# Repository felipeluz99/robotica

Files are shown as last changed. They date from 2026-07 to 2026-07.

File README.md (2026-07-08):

# Empilhadeira Autônoma

Turma 3VB - Grupo 3

Felipe Luz machado
Gabriel Cavalleiro
Henrique Conti
Lucas Erbisti

Documentação do projeto de uma empilhadeira capaz de operar em
dois modos: **controle manual** por um operador (via celular ou navegador) e
**busca automática** de um alvo marcado com uma etiqueta AprilTag, usando visão
computacional.

O objetivo deste documento é explicar como o sistema foi
organizado, o papel de cada peça de software e as ideias de controle por trás da
navegação autônoma.

---

## 1. Visão geral do sistema

O sistema é dividido em três programas que rodam em máquinas diferentes e
conversam entre si:

| Arquivo | Onde roda | Papel |
|---|---|---|
| `index.html` | Navegador (celular/PC) | Interface do operador: joysticks, botões e painel de estado |
| `app.py` | Raspberry Pi 3 | "Cérebro": servidor web, visão computacional (AprilTag) e máquina de estados da missão |
| `motor.cpp` | ESP32-WROOM | "Medula": leitura dos encoders/giroscópio e controle PID dos motores |

A ideia central é uma **divisão de responsabilidades por camada**:

- O **navegador** só cuida da interface e envia a intenção do operador.
- A **Raspberry Pi** decide *o que fazer* (procurar, girar, alinhar), mas não
  fala diretamente com os motores.
- O **ESP32** cuida da parte de tempo real *duro*: ler encoders, fechar o laço
  PID de velocidade e acionar as pontes H. Ele nunca decide a estratégia da
  missão; apenas obedece a comandos simples de `throttle` (avanço), `yaw` (giro)
  e `fork` (garfo).

```mermaid
flowchart LR
    A[Celular / Navegador<br/>index.html] -- WebSocket / Socket.IO --> B[Raspberry Pi 3<br/>app.py]
    B -- USB serial / JSON --> C[ESP32-WROOM<br/>motor.cpp]
    C -- Telemetria JSON --> B
    B -- status / apriltags --> A
    D[Câmera USB] --> B
    E[Encoders + MPU6050] --> C
    C --> F[Motores M1 / M2 / M3]
```

Existem, portanto, **dois canais de comunicação distintos**:

1. **Navegador ⇄ Raspberry Pi:** WebSocket (biblioteca Socket.IO).
2. **Raspberry Pi ⇄ ESP32:** porta serial USB, trocando linhas de texto em
   formato JSON.

---

## 2. O robô por dentro (hardware controlado)

O ESP32 controla três motores DC com encoder de quadratura:

- **M1 e M2** — rodas de tração (lado esquerdo e direito). A locomoção é
  **diferencial**: avançar é girar as duas rodas juntas; virar é girar uma mais
  que a outra.
- **M3** — motor do **garfo** (subir/descer a carga).

Cada motor tem uma ponte H com dois pinos de direção e um pino de PWM
(`enable`). O ESP32 também lê um giroscópio/acelerômetro **MPU6050** por I²C, que
fornece o ângulo de rotação (yaw) usado para fechar giros precisos de 90° e 180°
no modo automático.

Os pinos principais definidos em `motor.cpp`:

| Função | GPIO |
|---|---|
| M1 — direção A / B / PWM | 12 / 14 / 13 |
| M1 — encoder A / B | 34 / 35 |
| M2 — direção A / B / PWM | 27 / 26 / 25 |
| M2 — encoder A / B | 39 (VN) / 36 (VP) |
| M3 (garfo) — direção A / B / PWM | 23 / 22 / 5 |
| M3 — encoder A / B | 18 / 19 |
| MPU6050 — I²C SDA / SCL | 21 / 4 |
| Alimentação dos encoders — VCC / GND por GPIO | 32 (HIGH) / 33 (LOW) |

---

## 3. Diagrama elétrico

A montagem elétrica do protótipo reúne a Raspberry Pi, o ESP32, as pontes H, os
motores com encoder, o sensor MPU6050, a câmera USB e a alimentação do sistema. O
diagrama abaixo serve como referência para entender as ligações físicas entre os
módulos e facilitar a montagem, manutenção e depuração do robô.

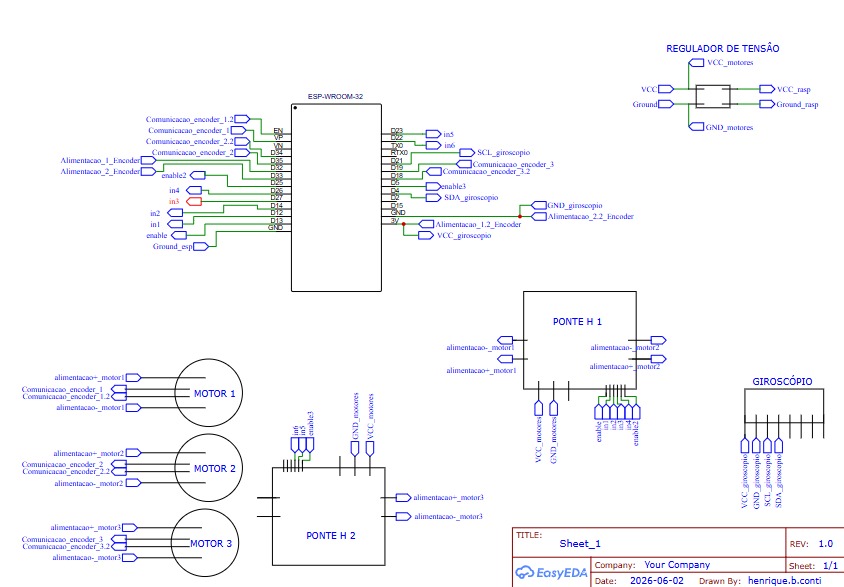
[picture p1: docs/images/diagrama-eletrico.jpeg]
Diagrama elétrico


---

## 4. Comunicação

### 4.1 Navegador ⇄ Raspberry Pi (WebSocket / Socket.IO)

O `app.py` sobe um servidor Flask com Socket.IO. O navegador (`index.html`) se
conecta e a partir daí a troca é toda por **eventos**, em tempo real, sem
recarregar a página. O WebSocket foi escolhido porque o controle precisa de
mensagens frequentes e de baixa latência nos dois sentidos.

**Eventos que o navegador envia para a Raspberry:**

| Evento | Conteúdo | Efeito |
|---|---|---|
| `set_target` | `{ tag_id }` | Define qual AprilTag procurar (só no modo MANUAL) |
| `mode` | `{ mode: "MANUAL" \| "AUTO" }` | Alterna entre controle manual e busca automática |
| `control` | `{ throttle, yaw, fork }` | Comando dos joysticks (só tem efeito no modo MANUAL) |
| `reset_yaw` | — | Zera o ângulo de yaw integrado no ESP32 |
| `calibrate_gyro` | — | Recalibra o giroscópio (robô precisa estar parado) |

**Eventos que a Raspberry envia de volta para o navegador:**

| Evento | Uso |
|---|-----|
| `status` | Estado da missão: modo, estado, fase, tag alvo, giroscópio, mensagem |
| `apriltags` | Tags detectadas na câmera e a pose da tag alvo |
| `telemetry` | Telemetria bruta repassada do ESP32 (RPM, PWM, garfo, giroscópio) |
| `target_result` / `mode_result` | Confirmação (ok/erro) dos comandos acima |

A interface tem três joysticks (biblioteca *nipplejs*): avanço/ré, giro e garfo.
Cada movimento do joystick vira um valor entre −1 e +1 e é enviado no evento
`control`. Para robustez, o navegador **reenvia o último comando a cada 150 ms**,
para o caso de o operador segurar o joystick parado sem gerar novos eventos.

### 4.2 Raspberry Pi ⇄ ESP32 (serial USB, JSON por linha)

A Raspberry manda para o ESP32 uma linha JSON por comando, por exemplo:

```json
{"throttle":0.24,"yaw":0.0,"fork":0.0,"mode":"AUTO","state":"BUSCA","phase":"AVANCAR"}
```

- `throttle` e `yaw` (−1 a +1) definem a velocidade e o giro desejados.
- `fork` (−1 a +1) comanda o motor do garfo.
- `mode`, `state`, `phase` são apenas informativos (usados no ESP32 para debug e
  para acender o LED de estado).
- Campos especiais como `reset_yaw` e `calibrate_gyro` disparam ações pontuais no
  giroscópio.

O ESP32 responde com um `ack` a cada comando aceito e, periodicamente (a cada
500 ms), envia um bloco de **telemetria** com RPM medido, PWM aplicado, posição
do garfo e a orientação do giroscópio. A Raspberry lê essa telemetria numa thread
separada e repassa ao navegador.

**Segurança por timeout:** se o ESP32 passar mais de **1 segundo** sem receber um
comando válido, ele **para todos os motores** sozinho. Por isso a Raspberry
mantém um laço reenviando o comando manual em frequência fixa — se a conexão cair
(navegador fechado, Wi-Fi ruim), o robô para em vez de sair descontrolado.

---

## 5. Visão computacional (AprilTag)

A navegação autônoma se apoia em **AprilTags**: etiquetas quadradas parecidas com
QR codes, porém projetadas para serem detectadas de forma rápida e robusta, com
estimativa de posição e orientação. Cada alvo da arena tem uma tag com um número
(ID) diferente.

O `app.py` usa a biblioteca `pupil_apriltags`. A cada quadro da câmera, o
programa:

1. Converte a imagem para tons de cinza e aplica equalização de histograma (ajuda
   quando a iluminação varia).
2. Detecta as tags visíveis e, para cada uma, estima a **pose 3D**.
3. Extrai o essencial: o ID e a posição da tag em relação à câmera —
   principalmente `x_mm` (deslocamento lateral) e `z_mm` (distância para frente).

Duas decisões importantes de projeto:

- **Não há streaming de vídeo.** A câmera é lida só para detectar tags; a imagem
  não é codificada nem enviada. Isso alivia bastante a CPU da Raspberry Pi 3 e
  melhora a taxa de detecção.
- **Memória temporal da tag.** A detecção pode falhar em quadros isolados mesmo
  com a tag parada na frente da câmera. Para o controle não "piscar", a última
  pose válida é considerada boa por uma fração de segundo antes de a tag ser dada
  como perdida.

O eixo mais usado no controle é o `x_mm`: se a tag está à direita do centro da
imagem, o robô gira para a direita para centralizá-la; o `z_mm` diz o quanto
ainda falta para chegar à distância de parada.

---

## 6. Controle PID dos motores (no ESP32)

Aqui está a parte de controle de baixo nível. Cada roda de tração (M1 e M2) tem
seu próprio controlador **PID de velocidade**, rodando no ESP32 a cada 100 ms.

A ideia do PID, em uma frase: ele compara a velocidade **desejada** (setpoint, em
RPM) com a velocidade **medida** pelo encoder e ajusta o PWM do motor para
eliminar a diferença (o *erro*).

- **P (proporcional):** reage ao erro atual — quanto maior a diferença, mais
  forte a correção.
- **I (integral):** acumula o erro ao longo do tempo — corrige aquele "resto"
  teimoso que o P sozinho não zera (por exemplo, atrito).
- **D (derivativo):** reage à velocidade de variação — ajuda a suavizar e evitar
  oscilação.

No código, os ganhos usados são `Kp = 2.0`, `Ki = 0.30`, `Kd = 0.0` (ou seja, na
prática um controlador **PI**, sem termo derivativo).

O laço de controle faz, em ordem:

```mermaid
flowchart TD
    A[Lê pulsos do encoder] --> B[Calcula RPM medido]
    B --> C[Erro = setpoint - RPM]
    C --> D[PID gera intensidade de PWM]
    D --> E[Define direção pelo sinal do comando]
    E --> F[Aplica PWM na ponte H]
```

Cuidados de engenharia já embutidos no PID:

- **Anti-windup:** o termo integral não continua acumulando quando a saída já está
  saturada (PWM no máximo ou no mínimo). Sem isso, o robô responderia com atraso
  depois de uma saturação.
- **Reset na troca de sentido:** ao inverter a direção do motor, o PID é
  reiniciado, evitando "arrasto" do estado anterior.
- **Zona morta / setpoint baixo:** setpoints muito pequenos zeram o motor, em vez
  de ficar zumbindo.

### Da intenção do operador aos dois motores (mixagem diferencial)

Os comandos chegam como `throttle` (avanço) e `yaw` (giro), mas os motores são
esquerdo e direito. A conversão é a mixagem clássica de acionamento diferencial:

```
comando_M1 = throttle + yaw
comando_M2 = throttle - yaw
```

Se a soma passar de 1, os dois valores são normalizados proporcionalmente (para
não distorcer a curva). Depois, cada comando (−1 a +1) é multiplicado pelo RPM
máximo para virar o setpoint de cada PID.

O **garfo (M3)** não usa PID de velocidade: o valor de `fork` é convertido
diretamente em PWM, com um mínimo para vencer o atrito e um máximo de segurança.

### Giroscópio: yaw por integração

O ângulo de rotação (yaw) usado no modo automático **não** vem do acelerômetro;
ele é obtido **integrando** a velocidade angular do eixo Z do MPU6050 ao longo do
tempo. Para reduzir a deriva, o ESP32 calibra o *bias* do sensor na inicialização
(robô parado) e aplica pequenas zonas mortas. É esse yaw que permite fechar giros
de 90° e 180° com precisão razoável na busca.

---

## 7. A lógica da busca automática (máquina de estados)

Quando o operador informa uma tag e ativa o modo AUTO, a Raspberry passa a
comandar o robô sozinha. A estratégia é varrer a arena parando para "olhar" para
os lados: a arena tem posições longitudinais (fileiras) e, em cada uma, pode
haver uma tag à esquerda ou à direita.

### 7.1 Os quatro estados conceituais

Do ponto de vista da ideia de controle, o robô está sempre em uma de **quatro
situações**, combinando *o que está fazendo* (procurando o alvo × alinhando ao
alvo) com *como está se movendo* (parado × em movimento):

| Estado conceitual | O que acontece |
|---|---|
| **Buscando_parado** | Robô parado observando um lado, esperando confirmar se a tag está ali |
| **Buscando_movimento** | Robô girando 90°/180° ou avançando para a próxima fileira, ainda procurando |
| **Alinhando_movimento** | A tag alvo foi vista; o robô se move para centralizá-la e chegar à distância certa |
| **Alinhando_parado** | Robô já centralizado e na distância correta — alvo encontrado, aguardando o operador |

```mermaid
stateDiagram-v2
    [*] --> Buscando_parado
    Buscando_parado --> Buscando_movimento: terminou de observar
    Buscando_movimento --> Buscando_parado: chegou ao próximo ângulo/fileira
    Buscando_parado --> Alinhando_movimento: tag alvo apareceu
    Buscando_movimento --> Alinhando_movimento: tag alvo apareceu
    Alinhando_movimento --> Alinhando_parado: centralizado e na distância certa
    Alinhando_movimento --> Buscando_movimento: perdeu a tag e não recuperou
    Alinhando_parado --> [*]: operador assume (MANUAL) e levanta o garfo
```

### 7.2 Como isso aparece no código

Na implementação (`app.py`), esses quatro estados conceituais se desdobram em
fases mais detalhadas, controladas pela classe `ControladorMissao`. O estado
geral (`EstadoMissao`) pode ser `IDLE`, `BUSCA` ou `ENCONTRADO`; dentro de
`BUSCA`, uma **fase** (`FaseBusca`) diz exatamente o que fazer. O mapeamento:

| Estado conceitual | Fases correspondentes no código |
|---|---|
| Buscando_parado | `AGUARDANDO_GIRO`, `OBSERVAR_ESQUERDA`, `OBSERVAR_DIREITA` |
| Buscando_movimento | `GIRAR_ESQUERDA`, `GIRAR_DIREITA`, `RETORNAR_FRENTE`, `AVANCAR`, `GIRAR_RETORNO` |
| Alinhando_movimento | `ALINHAR` (corrigindo), `RECUPERAR_TAG` |
| Alinhando_parado | `ALINHAR` (estável) → estado `ENCONTRADO` |

O ciclo típico de uma fileira é: girar 90° à esquerda → observar → girar 180°
para o lado direito → observar → voltar ao centro → avançar ~20 cm até a próxima
fileira. A qualquer momento, se a tag alvo aparecer na câmera, o robô interrompe a
varredura e passa ao **alinhamento**.

### 7.3 O alinhamento final

No alinhamento, o controle é **visual**, guiado pela pose da AprilTag, com dois
laços proporcionais simples:

- **Centralizar (eixo X):** gira o robô proporcionalmente ao `x_mm` da tag, até a
  tag ficar no centro da imagem.
- **Aproximar (eixo Z):** avança proporcionalmente à diferença entre a distância
  atual (`z_mm`) e a distância de parada desejada (150 mm).

Para não avançar torto, o robô **centraliza primeiro**: se o erro lateral for
grande, o avanço é bloqueado até a tag estar razoavelmente no centro. O alvo só é
declarado **encontrado** depois de o robô ficar centralizado e na distância certa
por várias amostras seguidas (evita declarar sucesso em um acerto momentâneo).

Se a tag sair do quadro durante o alinhamento, entra a fase `RECUPERAR_TAG`: o
robô faz uma pequena varredura para os dois lados tentando reencontrá-la; se não
conseguir em alguns segundos, volta a procurar do zero a partir da posição atual.

---

## 8. Segurança e robustez

Alguns cuidados que valem destaque, porque foram pensados justamente para o robô
não "fugir" do controle:

- **Timeout no ESP32 (1 s):** sem comando válido, os motores param sozinhos.
- **Reenvio periódico do comando manual:** mantém o robô "vivo" quando o operador
  segura o joystick, e garante a parada se o navegador desconectar.
- **Modo verificado nos dois lados:** o joystick é ignorado se o modo não for
  MANUAL, tanto no navegador quanto no servidor.
- **Sem giroscópio válido, sem movimento automático:** se a telemetria do yaw não
  estiver confiável, a máquina de estados mantém o robô parado.

---

## 9. Como executar

**No ESP32:** abrir `motor.cpp` no Arduino IDE, instalar as bibliotecas
`ArduinoJson`, `ESP32Encoder`, `Adafruit_MPU6050` e `Adafruit_Unified_Sensor`, e
gravar o sketch. Manter o robô parado durante a calibração inicial do
giroscópio (~1,6 s).

**Na Raspberry Pi:** instalar as dependências e rodar o servidor:

```bash
pip install flask flask-socketio pyserial opencv-python numpy pupil-apriltags
python app.py
```

O servidor sobe em `http://<ip-da-raspberry>:5000`. Basta abrir esse endereço no
navegador do celular (na mesma rede) para acessar a interface de controle. O
ESP32 deve estar conectado por USB à Raspberry (detectado automaticamente em
`/dev/ttyUSB*` ou `/dev/ttyACM*`).

**Uso básico:**

1. Conectar-se à interface e confirmar o indicador **Online**.
2. No modo MANUAL, digitar o número da AprilTag alvo e definir.
3. Ativar o modo **AUTO** — o robô inicia a busca.
4. Ao encontrar e alinhar (estado ENCONTRADO), voltar para **MANUAL** para
   assumir o controle e levantar o garfo.

---

## 10. Estrutura do repositório

```
.
├── app.py                         # Raspberry Pi: servidor web, visão (AprilTag) e máquina de estados
├── motor.cpp                      # ESP32: encoders, giroscópio, PID e acionamento dos motores
├── index.html                     # Interface web do operador (joysticks e painel de estado)
├── styles.css                     # Estilos adicionais da interface
├── docs/
│   └── images/
│       └── diagrama-eletrico.jpg  # Foto do diagrama elétrico da montagem
└── README.md                      # Este documento
```

---

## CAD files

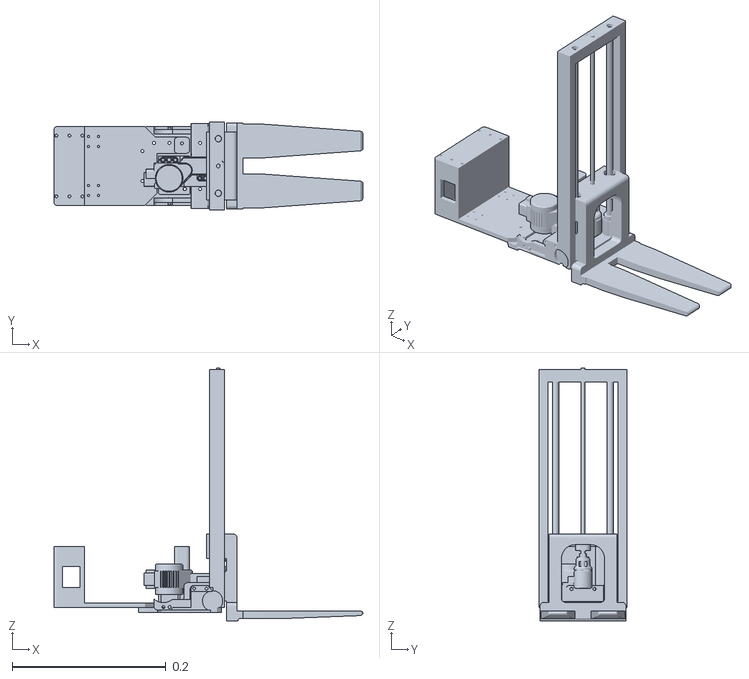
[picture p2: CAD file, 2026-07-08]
cad/Assembly 2.stl
0.402 x 0.114 x 0.329

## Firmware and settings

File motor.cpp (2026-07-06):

#include <Arduino.h>
#include <ArduinoJson.h>
#include <math.h>
#include <ESP32Encoder.h>
#include <Wire.h>
#include <Adafruit_MPU6050.h>
#include <Adafruit_Sensor.h>
#include <string.h>

// =====================================================
// CONFIGURAÇÕES DE DEBUG
// =====================================================
//
// ATENÇÃO: no modo USB, o debug compartilha a MESMA porta
// dos comandos JSON. Se ligar DEBUG_ATIVO com a Raspberry
// conectada, os prints de debug vão se misturar com os
// comandos/telemetria no mesmo canal. Use DEBUG_ATIVO = true
// apenas em bancada (Serial Monitor, sem a Pi), ou faça a Pi
// ignorar toda linha que não comece com '{'.

// Coloque true apenas para diagnóstico em bancada.
const bool DEBUG_ATIVO = false;

// Mostra cada JSON completo recebido.
const bool DEBUG_JSON_RECEBIDO = false;

// Mostra cada byte recebido pela UART.
// Deixe false normalmente, pois gera muitos prints.
const bool DEBUG_BYTES_UART = false;

// Mostra periodicamente RPM, setpoints, PWM, erros e pulsos.
const bool DEBUG_CONTROLE = true;

// Intervalo entre relatórios periódicos.
const unsigned long INTERVALO_DEBUG_MS = 300;

unsigned long instanteDebugAnterior = 0;

// Macro para prints formatados somente pela USB.
#define DEBUGF(...)                         \
  do {                                      \
    if (DEBUG_ATIVO) {                      \
      Serial.printf(__VA_ARGS__);           \
    }                                       \
  } while (0)

#define DEBUG_PRINT(texto)                   \
  do {                                      \
    if (DEBUG_ATIVO) {                      \
      Serial.print(texto);                  \
    }                                       \
  } while (0)

#define DEBUG_PRINTLN(texto)                 \
  do {                                      \
    if (DEBUG_ATIVO) {                      \
      Serial.println(texto);                \
    }                                       \
  } while (0)

// =====================================================
// COMUNICAÇÃO SERIAL
// =====================================================

// USB nativo do ESP32 (conector micro-USB).
// É por aqui que entram os comandos JSON da Raspberry Pi
// e saem o ack e a telemetria. É a MESMA porta usada para
// gravar o sketch e (opcionalmente) para debug.
const uint32_t BAUD_USB = 115200;

// =====================================================
// LED RGB NATIVO OPCIONAL
// =====================================================
// ESP32-WROOM comum normalmente não possui LED RGB nativo.
// Se sua placa for uma ESP32-S3/C3 com LED RGB endereçável nativo,
// coloque USAR_LED_RGB_NATIVO em 1 e ajuste o pino abaixo.
// Em muitas ESP32-S3 DevKit, o LED RGB nativo fica no GPIO48.

#define USAR_LED_RGB_NATIVO 0
#define PINO_LED_RGB_NATIVO 48


// =====================================================
// GIROSCÓPIO MPU6050 — BIBLIOTECA ADAFRUIT
// =====================================================
// Requer, no Arduino IDE:
//   1) Adafruit MPU6050
//   2) Adafruit Unified Sensor
//   3) Adafruit BusIO
//
// GPIO22 já é usado pelo motor 3 neste projeto. Por isso o I2C foi
// deslocado para GPIO16 (SDA) e GPIO17 (SCL), ambos livres no mapa atual.
// O GY-521/MPU6050 deve ser alimentado em 3,3 V e compartilhar o GND do ESP32.

const int PINO_I2C_SDA = 21;
const int PINO_I2C_SCL = 4;
const uint8_t ENDERECO_MPU6050 = 0x68;

Adafruit_MPU6050 mpu;

const unsigned long INTERVALO_GIROSCOPIO_US = 5000;  // 200 Hz
const unsigned long INTERVALO_PRINT_ORIENTACAO_MS = 500;
const bool PRINT_ORIENTACAO = true;

bool giroscopioDisponivel = false;
float biasGiroXDps = 0.0f;
float biasGiroYDps = 0.0f;
float biasGiroZDps = 0.0f;
float velocidadeGiroXDps = 0.0f;
float velocidadeGiroYDps = 0.0f;
float velocidadeGiroZDps = 0.0f;
float anguloRollGraus = 0.0f;
float anguloPitchGraus = 0.0f;
float anguloYawGraus = 0.0f;
float temperaturaMpuC = 0.0f;
unsigned long ultimoGiroscopioUs = 0;
unsigned long ultimoPrintOrientacaoMs = 0;

float normalizarAnguloGraus(float angulo) {
  while (angulo > 180.0f) angulo -= 360.0f;
  while (angulo <= -180.0f) angulo += 360.0f;
  return angulo;
}

void zerarYawGiroscopio() {
  anguloYawGraus = 0.0f;
  ultimoGiroscopioUs = micros();
}

void calcularRollPitchPorAcelerometro(const sensors_event_t &aceleracao) {
  float ax = aceleracao.acceleration.x;
  float ay = aceleracao.acceleration.y;
  float az = aceleracao.acceleration.z;

  // Convenção simples para debug:
  // roll  = inclinação lateral
  // pitch = inclinação para frente/trás
  // yaw   = giro horizontal integrado pelo giroscópio Z
  anguloRollGraus = atan2f(ay, az) * 180.0f / PI;
  anguloPitchGraus = atan2f(-ax, sqrtf(ay * ay + az * az)) * 180.0f / PI;
}

void imprimirOrientacaoSeNecessario(unsigned long agoraMs) {
  if (!PRINT_ORIENTACAO) {
    return;
  }

  if (agoraMs - ultimoPrintOrientacaoMs < INTERVALO_PRINT_ORIENTACAO_MS) {
    return;
  }

  ultimoPrintOrientacaoMs = agoraMs;

  // Linha não-JSON de propósito: o app.py ignora linhas que não começam com '{'.
  Serial.print("[ORIENTACAO] roll=");
  Serial.print(anguloRollGraus, 1);
  Serial.print(" deg | pitch=");
  Serial.print(anguloPitchGraus, 1);
  Serial.print(" deg | yaw=");
  Serial.print(anguloYawGraus, 1);
  Serial.print(" deg | gx=");
  Serial.print(velocidadeGiroXDps, 2);
  Serial.print(" dps | gy=");
  Serial.print(velocidadeGiroYDps, 2);
  Serial.print(" dps | gz=");
  Serial.print(velocidadeGiroZDps, 2);
  Serial.println(" dps");
}

bool inicializarGiroscopio() {
  Wire.begin(PINO_I2C_SDA, PINO_I2C_SCL);
  Wire.setClock(400000);
  delay(50);

  if (!mpu.begin(ENDERECO_MPU6050, &Wire)) {
    Serial.println("{\"gyro_error\":\"mpu6050_sem_resposta_adafruit\"}");
    return false;
  }

  mpu.setAccelerometerRange(MPU6050_RANGE_8_G);
  mpu.setGyroRange(MPU6050_RANGE_250_DEG);
  mpu.setFilterBandwidth(MPU6050_BAND_21_HZ);
  delay(100);

  // Calibração do bias do giroscópio.
  // O robô deve ficar completamente parado durante esta etapa.
  const int AMOSTRAS_CALIBRACAO = 800;
  double somaX = 0.0;
  double somaY = 0.0;
  double somaZ = 0.0;
  int amostrasValidas = 0;

  for (int i = 0; i < AMOSTRAS_CALIBRACAO; i++) {
    sensors_event_t aceleracao;
    sensors_event_t giro;
    sensors_event_t temperatura;

    if (mpu.getEvent(&aceleracao, &giro, &temperatura)) {
      somaX += giro.gyro.x * 180.0 / PI;
      somaY += giro.gyro.y * 180.0 / PI;
      somaZ += giro.gyro.z * 180.0 / PI;
      amostrasValidas++;
      calcularRollPitchPorAcelerometro(aceleracao);
      temperaturaMpuC = temperatura.temperature;
    }
    delay(2);
  }

  if (amostrasValidas < AMOSTRAS_CALIBRACAO * 0.8f) {
    Serial.println("{\"gyro_error\":\"falha_na_calibracao_adafruit\"}");
    return false;
  }

  biasGiroXDps = static_cast<float>(somaX / amostrasValidas);
  biasGiroYDps = static_cast<float>(somaY / amostrasValidas);
  biasGiroZDps = static_cast<float>(somaZ / amostrasValidas);

  velocidadeGiroXDps = 0.0f;
  velocidadeGiroYDps = 0.0f;
  velocidadeGiroZDps = 0.0f;
  anguloYawGraus = 0.0f;
  ultimoGiroscopioUs = micros();
  ultimoPrintOrientacaoMs = millis();

  Serial.print("{\"gyro\":\"inicializado_adafruit\",\"bias_x_dps\":");
  Serial.print(biasGiroXDps, 4);
  Serial.print(",\"bias_y_dps\":");
  Serial.print(biasGiroYDps, 4);
  Serial.print(",\"bias_z_dps\":");
  Serial.print(biasGiroZDps, 4);
  Serial.println("}");
  return true;
}

void atualizarGiroscopio() {
  if (!giroscopioDisponivel) {
    return;
  }

  unsigned long agoraUs = micros();
  unsigned long intervaloUs = agoraUs - ultimoGiroscopioUs;

  if (intervaloUs < INTERVALO_GIROSCOPIO_US) {
    return;
  }

  ultimoGiroscopioUs = agoraUs;
  float dt = intervaloUs / 1000000.0f;

  // Ignora intervalos absurdos para não integrar saltos após bloqueios.
  if (dt <= 0.0f || dt > 0.1f) {
    return;
  }

  sensors_event_t aceleracao;
  sensors_event_t giro;
  sensors_event_t temperatura;

  if (!mpu.getEvent(&aceleracao, &giro, &temperatura)) {
    return;
  }

  velocidadeGiroXDps = giro.gyro.x * 180.0f / PI - biasGiroXDps;
  velocidadeGiroYDps = giro.gyro.y * 180.0f / PI - biasGiroYDps;
  velocidadeGiroZDps = giro.gyro.z * 180.0f / PI - biasGiroZDps;

  // Pequenas zonas mortas reduzem deriva quando o robô está parado.
  if (fabsf(velocidadeGiroXDps) < 0.35f) velocidadeGiroXDps = 0.0f;
  if (fabsf(velocidadeGiroYDps) < 0.35f) velocidadeGiroYDps = 0.0f;
  if (fabsf(velocidadeGiroZDps) < 0.35f) velocidadeGiroZDps = 0.0f;

  calcularRollPitchPorAcelerometro(aceleracao);
  temperaturaMpuC = temperatura.temperature;

  // O yaw não vem do acelerômetro; ele é integrado do giro Z.
  // Ele serve ao app.py para fechar giros de 90°/180° no AUTO.
  anguloYawGraus = normalizarAnguloGraus(
    anguloYawGraus + velocidadeGiroZDps * dt
  );

  imprimirOrientacaoSeNecessario(millis());
}

// Tempo sem comandos antes da parada automática.
const unsigned long TIMEOUT_COMANDO_MS = 1000;

// =====================================================
// ALIMENTAÇÃO DOS ENCODERS POR GPIO
// =====================================================

// GPIO32 mantido em HIGH.
const int pinoVccEncoder = 32;

// GPIO33 mantido em LOW.
const int pinoGndEncoder = 33;

const unsigned long TEMPO_ESTABILIZACAO_ENCODER_MS = 100;

// =====================================================
// MOTOR 1
// =====================================================

const int pinDirecaoA_M1 = 12;
const int pinDirecaoB_M1 = 14;
const int pinoEnable_M1  = 13;

const int enc1_A = 34;
const int enc1_B = 35;

ESP32Encoder encoderM1;
long oldPosM1 = 0;

float rotacoesM1 = 0.0f;
float setpointM1 = 0.0f;

int pwmM1 = 0;
int sentidoAnteriorM1 = 0;

// =====================================================
// MOTOR 2
// =====================================================

const int pinDirecaoA_M2 = 27;
const int pinDirecaoB_M2 = 26;
const int pinoEnable_M2  = 25; 

// GPIO36 aparece como VP.
// GPIO39 aparece como VN.
const int enc2_A = 39;
const int enc2_B = 36;

ESP32Encoder encoderM2;
long oldPosM2 = 0;

float rotacoesM2 = 0.0f;
float setpointM2 = 0.0f;

int pwmM2 = 0;
int sentidoAnteriorM2 = 0;

// =====================================================
// MOTOR 3
// =====================================================

const int pinDirecaoA_M3 = 23;   // in5
const int pinDirecaoB_M3 = 22;   // in6
const int pinoEnable_M3  = 5;    // enable3 (PWM)

const int enc3_A = 18;
const int enc3_B = 19;

ESP32Encoder encoderM3;
long oldPosM3 = 0;

float rotacoesM3 = 0.0f;
float setpointM3 = 0.0f;

int pwmM3 = 0;
int sentidoAnteriorM3 = 0;

// Últimos deltas para diagnóstico.
long ultimoDeltaPulsosM1 = 0;
long ultimoDeltaPulsosM2 = 0;
long ultimoDeltaPulsosM3 = 0;

// =====================================================
// CONFIGURAÇÕES DOS MOTORES E ENCODERS
// =====================================================

// Ajustar conforme a resolução real do encoder.
const float PULSOS_POR_REVOLUCAO = 720.0f;

// RPM para comando máximo.
const float RPM_MAXIMO = 130f;

// Inverta caso o motor físico esteja no sentido contrário.
const bool INVERTER_MOTOR_1 = false;
const bool INVERTER_MOTOR_2 = false;
const bool INVERTER_MOTOR_3 = false;

// Inverta caso o encoder informe sinal contrário.
const bool INVERTER_ENCODER_1 = false;
const bool INVERTER_ENCODER_2 = false;
const bool INVERTER_ENCODER_3 = false;

// =====================================================
// CONTROLE MANUAL DO GARFO / MOTOR 3
// =====================================================
// O terceiro joystick da interface envia fork entre -1.0 e +1.0.
// O valor é convertido diretamente em PWM para o motor do garfo,
// seguindo a mesma lógica manual dos outros comandos do robô.

const long GARFO_PULSOS_CURSO_TOTAL = 7200;  // mantido para telemetria de posição
const int PWM_MIN_GARFO = 60;
const int PWM_MAX_GARFO = 180;

float forkCommand = 0.0f;
float forkPositionAtual = 0.0f;
long posicaoGarfoPulsos = 0;
long alvoGarfoPulsos = 0;
long erroGarfoPulsos = 0;

// Estado lógico recebido da Raspberry/interface. Usado na telemetria
// e no LED RGB nativo, caso exista.
char modoEmpilhadeira[16] = "MANUAL";
char estadoEmpilhadeira[24] = "IDLE";
char faseEmpilhadeira[32] = "PARADO";
bool timeoutAtivo = false;

// PWM acima do qual a ausência de pulsos gera alerta.
const int PWM_ALERTA_ENCODER = 70;

// =====================================================
// INTERVALOS
// =====================================================

const unsigned long INTERVALO_CONTROLE_MS = 100;
const unsigned long INTERVALO_TELEMETRIA_MS = 500;

unsigned long instanteControleAnterior = 0;
unsigned long instanteTelemetriaAnterior = 0;
unsigned long ultimoComandoRecebido = 0;

// =====================================================
// COMANDOS
// =====================================================

// Faixa:
// throttle: -1.0 até +1.0
// yaw:      -1.0 até +1.0

float throttle = 0.0f;
float yaw = 0.0f;

bool comandoRecebido = false;

// Contadores de diagnóstico.
unsigned long totalJsonValidos = 0;
unsigned long totalJsonInvalidos = 0;
unsigned long totalBytesRecebidos = 0;
unsigned long totalTimeouts = 0;

// =====================================================
// PID
// =====================================================

struct ControladorPID {
  float kp;
  float ki;
  float kd;

  float integral;
  float medidaAnterior;

  bool iniciado;
};

ControladorPID pidM1 = {
  2.0f,
  0.30f,
  0.00f,
  0.0f,
  0.0f,
  false
};

ControladorPID pidM2 = {
  2.0f,
  0.30f,
  0.00f,
  0.0f,
  0.0f,
  false
};

const float LIMITE_INTEGRAL = 200.0f;

// =====================================================
// INTERRUPÇÕES DOS ENCODERS
// =====================================================

// Não coloque Serial.print dentro das interrupções.


// =====================================================
// MENSAGENS PARA RASPBERRY
// =====================================================

// Envia resposta para o Raspberry e replica na USB.
void enviarMensagem(const char *mensagem) {
  Serial.println(mensagem);

  if (DEBUG_ATIVO) {
    Serial.print("[TX RASPBERRY] ");
    Serial.println(mensagem);
  }
}

// =====================================================
// ALIMENTAÇÃO DOS ENCODERS
// =====================================================

void ligarAlimentacaoEncoders() {
  DEBUG_PRINTLN();
  DEBUG_PRINTLN("[ENCODER POWER] Iniciando alimentação...");

  // Primeiro estabelece o GND relativo.
  digitalWrite(pinoGndEncoder, LOW);
  pinMode(pinoGndEncoder, OUTPUT);
  digitalWrite(pinoGndEncoder, LOW);

  DEBUGF(
    "[ENCODER POWER] GPIO%d configurado como GND relativo.\n",
    pinoGndEncoder
  );

  // Mantém VCC desligado inicialmente.
  digitalWrite(pinoVccEncoder, LOW);
  pinMode(pinoVccEncoder, OUTPUT);
  digitalWrite(pinoVccEncoder, LOW);

  DEBUGF(
    "[ENCODER POWER] GPIO%d configurado como saída inicialmente LOW.\n",
    pinoVccEncoder
  );

  delay(10);

  // Energiza os encoders.
  digitalWrite(pinoVccEncoder, HIGH);

  DEBUGF(
    "[ENCODER POWER] GPIO%d colocado em HIGH.\n",
    pinoVccEncoder
  );

  delay(TEMPO_ESTABILIZACAO_ENCODER_MS);

  int estadoVcc = digitalRead(pinoVccEncoder);
  int estadoGnd = digitalRead(pinoGndEncoder);

  DEBUGF(
    "[ENCODER POWER] Leitura GPIO%d VCC = %s\n",
    pinoVccEncoder,
    estadoVcc == HIGH ? "HIGH" : "LOW"
  );

  DEBUGF(
    "[ENCODER POWER] Leitura GPIO%d GND = %s\n",
    pinoGndEncoder,
    estadoGnd == LOW ? "LOW" : "HIGH"
  );

  if (estadoVcc != HIGH) {
    DEBUG_PRINTLN(
      "[ERRO] GPIO de alimentação do encoder não permaneceu HIGH."
    );
  }

  if (estadoGnd != LOW) {
    DEBUG_PRINTLN(
      "[ERRO] GPIO de GND relativo do encoder não permaneceu LOW."
    );
  }

  DEBUG_PRINTLN("[ENCODER POWER] Alimentação inicializada.");
}

void desligarAlimentacaoEncoders() {
  DEBUG_PRINTLN("[ENCODER POWER] Desligando alimentação.");

  digitalWrite(pinoVccEncoder, LOW);
  digitalWrite(pinoGndEncoder, LOW);
}

// =====================================================
// DEBUG VISUAL POR LED RGB NATIVO OPCIONAL
// =====================================================

void copiarTextoSeguro(char *destino, size_t tamanho, const char *origem) {
  if (destino == nullptr || tamanho == 0 || origem == nullptr) {
    return;
  }

  strncpy(destino, origem, tamanho - 1);
  destino[tamanho - 1] = '\0';
}

void escreverLedRgb(uint8_t r, uint8_t g, uint8_t b) {
#if USAR_LED_RGB_NATIVO
  rgbLedWrite(PINO_LED_RGB_NATIVO, r, g, b);
#else
  (void)r;
  (void)g;
  (void)b;
#endif
}

void atualizarLedEstado() {
  if (timeoutAtivo) {
    escreverLedRgb(255, 0, 0);        // vermelho: timeout/erro
    return;
  }

  if (strcmp(estadoEmpilhadeira, "ENCONTRADO") == 0) {
    escreverLedRgb(0, 255, 0);        // verde: alvo encontrado
    return;
  }

  if (strcmp(faseEmpilhadeira, "RECUPERAR_TAG") == 0) {
    escreverLedRgb(180, 0, 255);      // roxo: recuperação da tag
    return;
  }

  if (strcmp(modoEmpilhadeira, "AUTO") == 0) {
    escreverLedRgb(255, 180, 0);      // amarelo/laranja: busca automática
    return;
  }

  if (strcmp(modoEmpilhadeira, "MANUAL") == 0) {
    escreverLedRgb(0, 0, 255);        // azul: manual
    return;
  }

  escreverLedRgb(255, 255, 255);      // branco: estado desconhecido
}

// =====================================================
// PID
// =====================================================

#define PID_ESCOLHIDO(indicePid) ((indicePid) == 2 ? pidM2 : pidM1)

void resetarPID(int indicePid) {
  ControladorPID &pid = PID_ESCOLHIDO(indicePid);
  pid.integral = 0.0f;
  pid.medidaAnterior = 0.0f;
  pid.iniciado = false;
}

float calcularPID(
  int indicePid,
  float setpoint,
  float medida,
  float dt
) {
  ControladorPID &pid = PID_ESCOLHIDO(indicePid);

  if (setpoint < 0.5f || dt <= 0.0f) {
    resetarPID(indicePid);
    return 0.0f;
  }

  float erro = setpoint - medida;
  float derivada = 0.0f;

  if (pid.iniciado) {
    derivada =
      -(medida - pid.medidaAnterior) / dt;
  }

  float integralCandidata =
    pid.integral + erro * dt;

  integralCandidata = constrain(
    integralCandidata,
    -LIMITE_INTEGRAL,
    LIMITE_INTEGRAL
  );

  float saidaCandidata =
    pid.kp * erro +
    pid.ki * integralCandidata +
    pid.kd * derivada;

  bool saturadoMaximo =
    saidaCandidata > 255.0f;

  bool saturadoMinimo =
    saidaCandidata < 0.0f;

  // Anti-windup.
  if (
    (!saturadoMaximo && !saturadoMinimo) ||
    (saturadoMaximo && erro < 0.0f) ||
    (saturadoMinimo && erro > 0.0f)
  ) {
    pid.integral = integralCandidata;
  }

  float saida =
    pid.kp * erro +
    pid.ki * pid.integral +
    pid.kd * derivada;

  pid.medidaAnterior = medida;
  pid.iniciado = true;

  return constrain(saida, 0.0f, 255.0f);
}

// =====================================================
// ACIONAMENTO DOS MOTORES
// =====================================================

void acionarMotor(
  int pinDirecaoA,
  int pinDirecaoB,
  int pinoEnable,
  float comandoPWM,
  bool inverterMotor
) {
  if (inverterMotor) {
    comandoPWM = -comandoPWM;
  }

  int pwm = constrain(
    static_cast<int>(roundf(fabsf(comandoPWM))),
    0,
    255
  );

  if (pwm == 0) {
    analogWrite(pinoEnable, 0);

    digitalWrite(pinDirecaoA, LOW);
    digitalWrite(pinDirecaoB, LOW);

    return;
  }

  if (comandoPWM > 0.0f) {
    digitalWrite(pinDirecaoA, LOW);
    digitalWrite(pinDirecaoB, HIGH);
  } else {
    digitalWrite(pinDirecaoA, HIGH);
    digitalWrite(pinDirecaoB, LOW);
  }

  analogWrite(pinoEnable, pwm);
}

// =====================================================
// CONTROLE INDIVIDUAL
// =====================================================

float controlarMotor(
  const char *nomeMotor,
  int indicePid,
  float setpoint,
  float rpmMedido,
  float dt,
  int &sentidoAnterior
) {
  int sentidoAtual = 0;

  if (setpoint > 0.5f) {
    sentidoAtual = 1;
  } else if (setpoint < -0.5f) {
    sentidoAtual = -1;
  }

  if (sentidoAtual == 0) {
    if (sentidoAnterior != 0) {
      DEBUGF(
        "[%s] Setpoint zerado. Reiniciando PID.\n",
        nomeMotor
      );
    }

    resetarPID(indicePid);
    sentidoAnterior = 0;

    return 0.0f;
  }

  if (
    sentidoAnterior != 0 &&
    sentidoAtual != sentidoAnterior
  ) {
    DEBUGF(
      "[%s] Mudança de direção detectada: %d -> %d. "
      "Reiniciando PID.\n",
      nomeMotor,
      sentidoAnterior,
      sentidoAtual
    );

    resetarPID(indicePid);
  }

  sentidoAnterior = sentidoAtual;

  float setpointAbsoluto =
    fabsf(setpoint);

  float rpmNoSentidoSolicitado =
    rpmMedido * static_cast<float>(sentidoAtual);

  float intensidadePWM = calcularPID(
    indicePid,
    setpointAbsoluto,
    rpmNoSentidoSolicitado,
    dt
  );

  return intensidadePWM *
         static_cast<float>(sentidoAtual);
}

// =====================================================
// SETPOINTS
// =====================================================

void atualizarSetpoints() {
  float throttleOriginal = throttle;
  float yawOriginal = yaw;

  throttle = constrain(
    throttle,
    -1.0f,
    1.0f
  );

  yaw = constrain(
    yaw,
    -1.0f,
    1.0f
  );
/*
  if (
    throttle != throttleOriginal ||
    yaw != yawOriginal
  ) {
//    DEBUGF(
      "[COMANDO] Valores limitados: throttle %.3f -> %.3f, "
      "yaw %.3f -> %.3f\n",
      throttleOriginal,
      throttle,
      yawOriginal,
      yaw
    );
  }
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
void loop() {
  unsigned long instanteAtual = millis();

  atualizarGiroscopio();
  receberDadosRaspberry();
  verificarTimeout(instanteAtual);
  executarControle(instanteAtual);
  enviarTelemetria(instanteAtual);
  atualizarLedEstado();
  imprimirDebugControle(instanteAtual);
}

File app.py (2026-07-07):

import glob
import json
import math
import threading
import time
from enum import Enum

import cv2
import numpy as np
import serial
from flask import Flask, render_template
from flask_socketio import SocketIO

try:
    from pupil_apriltags import Detector
except ImportError:
    Detector = None


# ============================================================
# CONFIGURAÇÕES GERAIS
# ============================================================

BAUD_ESP = 115200
CAMERA_ID = 0
LARGURA = 640
ALTURA = 480
FPS = 10
QUALIDADE_JPEG = 90

DETECTAR_APRILTAGS = True
TAMANHO_TAG_M = 0.048
FAMILIA_TAG = "tag25h9"
APRILTAG_TELEMETRY_INTERVAL = 0.20

# Imprime no terminal o tempo de detecção e os IDs vistos em cada frame.
# Útil para diagnosticar detecção intermitente. Desligue depois dos testes.
DEBUG_VISAO = True

# Filtro de falsos positivos ("tags fantasmas").
# hamming = bits corrigidos na decodificação (0 = perfeita).
# decision_margin = confiança; fantasmas típicos ficam abaixo de ~30,
# tags reais bem enquadradas ficam entre 50 e 150. Se tags reais
# começarem a ser rejeitadas, reduza MARGEM_DECISAO_MINIMA para 30.
HAMMING_MAXIMO = 0
MARGEM_DECISAO_MINIMA = 40.0

# ============================================================
# PARÂMETROS INICIAIS DA BUSCA
# Todos estes valores são de bancada e precisam ser calibrados.
# ============================================================

# A arena terá três posições longitudinais.
NUM_ESTACOES = 3

# Avanço aproximado entre duas posições. Como ainda não temos
# diâmetro de roda e relação pulsos/cm confirmados, nesta primeira versão
# o avanço é temporizado. Ajuste até o robô percorrer aproximadamente 20 cm.
TEMPO_AVANCO_20CM_S = 1.20
THROTTLE_BUSCA = 0.24

# Varredura de 360° em passos.
# O robô gira um passo, para, observa, e só então gira o próximo passo.
# Passos pequenos evitam o borrão de movimento que impede a detecção.
PASSO_VARREDURA_GRAUS = 30.0
NUM_PASSOS_VARREDURA = 12          # 12 x 30° = 360°
TEMPO_OBSERVACAO_PASSO_S = 0.50

# Giros fechados por giroscópio.
# Valores reduzidos: com passos de 30°, o teto antigo (0.42) fazia o robô
# partir quase na velocidade máxima em todo passo.
KP_GIRO = 0.010
YAW_GIRO_MAX = 0.26
YAW_GIRO_MIN = 0.13
TOLERANCIA_GIRO_GRAUS = 3.0
AMOSTRAS_GIRO_ESTAVEL = 4

# Em alguns chassis, o sinal de yaw pode estar invertido.
# Troque para -1.0 se o robô girar para o lado oposto.
SINAL_YAW_GIRO = 1.0

# Controle visual final.
DISTANCIA_FINAL_TAG_MM = 150.0
TOLERANCIA_X_MM = 20.0
TOLERANCIA_Z_MM = 25.0
KP_X_VISUAL = 0.0090
# KP_Z reduzido e teto de throttle baixado: antes o robô avançava saturado
# em 0.75 até ~83 mm do alvo. Agora aproxima com no máximo 0.35 e começa a
# desacelerar a ~100 mm do erro zero.
KP_Z_VISUAL = 0.0035
YAW_VISUAL_MAX = 0.30
THROTTLE_VISUAL_MAX = 0.35
# Piso do avanço: abaixo disso o robô não vence o atrito e "morre" antes
# do alvo. Só é aplicado fora da tolerância de distância.
THROTTLE_VISUAL_MIN = 0.14
AMOSTRAS_ALINHADO = 6

# Troque o sinal caso a correção visual vá para o lado errado.
SINAL_YAW_VISUAL = 1.0
SINAL_THROTTLE_VISUAL = 1.0

# A pose angular da AprilTag costuma ser mais ruidosa sem calibração de câmera.
# Por isso, nesta primeira versão o alinhamento final usa centralização X + distância Z.
USAR_ANGULO_DA_TAG = False
TOLERANCIA_ANGULO_TAG_GRAUS = 8.0
KP_ANGULO_TAG = 0.010

IDADE_MAXIMA_DETECCAO_S = 0.55
TAG_RETENCAO_INTERFACE_S = 1.00

# Recuperação de tag perdida.
# TEMPO_PERDA_TAG_S maior: a perda geralmente é borrão de movimento, e o
# robô parado por 1 s frequentemente redetecta sozinho, sem varrer nada.
TEMPO_PERDA_TAG_S = 1.0
TEMPO_RECUPERACAO_TAG_S = 4.0
# Varredura curta de recuperação: amplitude menor, período mais longo e
# teto de yaw próprio evitam o chicote (o alvo alternava mais rápido do
# que o robô conseguia alcançá-lo, mantendo o comando sempre no máximo).
AMPLITUDE_RECUPERACAO_GRAUS = 12.0
PERIODO_RECUPERACAO_S = 1.4
YAW_RECUPERACAO_MAX = 0.18

INTERVALO_LOOP_AUTONOMO_S = 0.05
INTERVALO_STATUS_S = 0.20

# Reenvio de comando manual pelo backend.
# O ESP32 tem timeout de 1 s; então o app.py passa a repetir o último
# comando manual em frequência fixa, em vez de depender apenas dos eventos
# ``move`` do joystick no navegador/celular.
INTERVALO_REENVIO_MANUAL_S = 0.10
TEMPO_MAX_COMANDO_MANUAL_SEM_ATUALIZACAO_S = 3.0


# ============================================================
# CONEXÃO SERIAL COM O ESP32
# ============================================================

serial_lock = threading.Lock()
ser = None
_ultimo_envio = 0.0

# Último comando manual recebido do navegador.
# O loop de reenvio usa estes valores para manter o ESP32 alimentado
# com throttle/yaw enquanto o operador segura o joystick parado.
manual_lock = threading.Lock()
ultimo_comando_manual = {
    "throttle": 0.0,
    "yaw": 0.0,
    "fork": 0.0,
}
instante_ultimo_comando_manual = 0.0


def estado_atual_para_esp():
    """Retorna o estado lógico atual para debug no ESP32/LED.

    A função tolera chamadas antes da criação do controlador.
    """
    try:
        status = controlador.status()
    except NameError:
        return {
            "mode": "MANUAL",
            "state": "IDLE",
            "phase": "PARADO",
            "target_tag": None,
        }

    return {
        "mode": status.get("mode", "MANUAL"),
        "state": status.get("state", "IDLE"),
        "phase": status.get("phase", "PARADO"),
        "target_tag": status.get("target_tag"),
    }


def anexar_estado_e_garfo(dados):
    """Anexa modo/estado/fase ao JSON enviado ao ESP32."""
    comando = dict(dados)
    estado = estado_atual_para_esp()

    comando.setdefault("mode", estado["mode"])
    comando.setdefault("state", estado["state"])
    comando.setdefault("phase", estado["phase"])

    if estado["target_tag"] is not None:
        comando.setdefault("target_tag", estado["target_tag"])

    comando.setdefault("fork", 0.0)
    return comando


def abrir_serial_esp(baud=BAUD_ESP):
    portas = glob.glob("/dev/ttyUSB*") + glob.glob("/dev/ttyACM*")
    if not portas:
        print("AVISO: nenhum ESP32 encontrado em /dev/ttyUSB* ou /dev/ttyACM*.")
        return None

    porta = portas[0]
    print(f"Abrindo ESP32 em {porta} @ {baud} baud")

    try:
        conexao = serial.Serial(porta, baud, timeout=0.2)
        time.sleep(2)
        conexao.reset_input_buffer()
        return conexao
    except Exception as erro:
        print("Erro ao abrir ESP32:", erro)
        return None
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
